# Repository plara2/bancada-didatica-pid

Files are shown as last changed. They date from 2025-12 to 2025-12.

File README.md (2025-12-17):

# 🌡️ Bancada Didática de Controle de Temperatura (Arduino + PID)

Este repositório contém todo o material necessário para reproduzir uma bancada didática de controle térmico de baixo custo. O projeto abrange desde a usinagem da planta mecânica e esquemáticos eletrônicos até o firmware para controle **On-Off** e **PID Digital**.

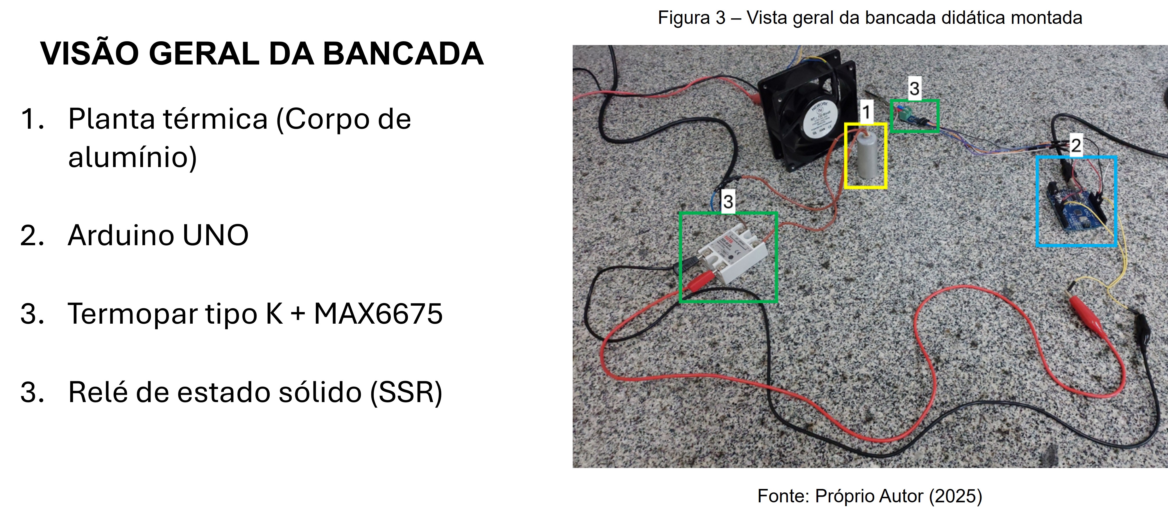
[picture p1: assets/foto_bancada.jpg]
Foto da Bancada Montada

[cite_start]*Figura: Visão geral da bancada com planta térmica, driver de potência e controlador[cite: 84].*

## 🎯 Visão Geral
[cite_start]O projeto utiliza um corpo de prova de alumínio usinado como planta térmica[cite: 92]. [cite_start]O objetivo é demonstrar na prática a diferença entre um controle simples (On-Off) e um controle proporcional-integral-derivativo (PID) sintonizado via método de Ziegler-Nichols[cite: 9].

* [cite_start]**Atuador:** Relé de Estado Sólido (SSR) com técnica de *Slow PWM* (Janela de 8s)[cite: 127, 128].
* [cite_start]**Sensor:** Termopar Tipo K com interface MAX6675[cite: 112, 113].
* [cite_start]**Controlador:** Arduino UNO (Amostragem de 250ms)[cite: 124].

## 📂 Estrutura do Repositório

### 1. Firmware (`/firmware`)
Contém os códigos fonte em C++ para Arduino IDE:
* **Control_PID:** Implementa o algoritmo PID completo usando a biblioteca `PID_v1`. [cite_start]Inclui rotinas de segurança contra falha do sensor e modulação temporal do relé [cite: 254-346].
* **Control_OnOff:** Implementa a lógica de histerese (±0,5°C) para fins comparativos [cite: 347-421].

**Dependências (Bibliotecas):**
* [cite_start][`MAX6675` da Adafruit](https://github.com/adafruit/MAX6675-library) [cite: 228]
* [cite_start][`PID` de Brett Beauregard](https://github.com/br3ttb/Arduino-PID-Library) [cite: 230]

### 2. Hardware Mecânico (`/hardware/mechanical`)
[cite_start]Arquivos para fabricação do corpo de prova cilíndrico (Ø26mm x 61mm)[cite: 93].
* [cite_start]📄 **Desenhos Técnicos:** Dimensões para usinagem dos furos do cartucho e rosca M6 do sensor.
* 🧊 **Modelos 3D:** Arquivos disponíveis em `.f3d` (Fusion 360) e `.step` (Universal).

### 3. Eletrônica (`/hardware/electronics`)
Projeto do circuito de acionamento e leitura.
* Disponível em formato PDF para consulta rápida.
* Arquivos fonte do **KiCad** para edição da PCB/Esquemático.

## 📊 Resultados Comparativos
A bancada permite visualizar claramente a diferença de desempenho entre as técnicas:

| Controle | Comportamento Observado |
| :--- | :--- |
| **On-Off** | Oscilação contínua de ~15°C (pico-a-pico) em torno do Setpoint[cite: 10, 197]. |
| **PID** | Estabilização no Setpoint (50°C) com erro estacionário desprezível após sintonia[cite: 10, 219]. |

Comparação PID vs OnOff
*Exemplo de resposta do sistema controlado via PID[cite: 202].*

## 🚀 Como Reproduzir
1.  **Usinagem:** Utilize os desenhos na pasta `mechanical` para usinar o bloco de alumínio.
2.  **Eletrônica:** Monte o circuito conforme o esquema na pasta `electronics` (Arduino + SSR + MAX6675)[cite: 115].
3.  **Software:** Instale as bibliotecas listadas acima, abra o arquivo `.ino` desejado na Arduino IDE e faça o upload.
4.  **Visualização:** Abra o *Serial Plotter* (115200 baud) para ver as curvas em tempo real[cite: 133].

## 📄 Licença
Este projeto é Open Source. Sinta-se livre para estudar, modificar e contribuir.

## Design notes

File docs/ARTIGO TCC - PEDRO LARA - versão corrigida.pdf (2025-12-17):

Rev. Bras. de Iniciação Científica (RBIC), IFSP Itapetininga, v.12, e025XXX, p. 1-3, 2025.

## Implementação Didática de Controle de Temperatura: Comparação entre PID Digital e On-Off

## Didactic Implementation of Temperature Control: Comparison between Digital PID and On-Off

## Implementación Didáctica de Control de Temperatura: Comparación entre PID Digital y On-Off

Pedro Augusto de Oliveira Lara¹
Cristhiano da Costa Herrera²

Resumo: O ensino de sistemas de controle muitas vezes carece de exemplos práticos que facilitem a visualização da teoria. Este trabalho apresenta o desenvolvimento de uma bancada didática para controle de temperatura, utilizando a plataforma Arduino. O sistema é composto por um corpo de prova de alumínio aquecido por resistência elétrica e monitorado por um termopar. A metodologia consistiu na implementação e comparação de duas estratégias: um controle clássico On-Off e um controlador PID digital, sintonizado pelo método de Ziegler-Nichols. Os resultados demonstraram que o controle On-Off gerou oscilações elevadas de 15°C, enquanto o PID estabilizou o sistema no setpoint de 50°C com erro estacionário desprezível, se comparado com o controle On-Off. Conclui-se que a bancada é eficaz para demonstrar conceitos de controle, embora a elevada inércia térmica da planta exija adaptações para uso em aulas experimentais de curta duração.
Palavras-chave: Controle PID. Bancada Didática. Arduino. Ziegler-Nichols. Controle de Temperatura.

Abstract: The teaching of control systems often lacks practical examples that facilitate the visualization of theoretical concepts. This work presents the development of a didactic test bench for temperature control, using the Arduino platform. The system is composed of an aluminum test body heated by an electrical resistance and monitored by a thermocouple. The methodology consisted of implementing and comparing two strategies: a classical On-Off control and a digital PID controller, tuned by the Ziegler–Nichols method. The results showed that the On-Off control generated high oscillations of 15 °C, while the PID stabilized the system at the 50 °C setpoint with negligible steady-state error when compared to the On-Off control. It is concluded that the test bench is effective for demonstrating control concepts, although the high thermal inertia of the plant requires adaptations for use in short-duration experimental classes.
Keywords: PID Control. Didactic Test Bench. Arduino. Ziegler–Nichols. Temperature Control.

Resumen: La enseñanza de sistemas de control a menudo carece de ejemplos prácticos que faciliten la visualización de la teoría. Este trabajo presenta el desarrollo de una bancada didáctica de bajo costo para el control de temperatura mediante la plataforma Arduino. El sistema consta de un cuerpo de prueba de aluminio calentado por una resistencia eléctrica y monitoreado por un termopar. La metodología incluyó la implementación y comparación de dos estrategias: un control clásico On-Off y un controlador PID digital sintonizado con el método de Ziegler–Nichols. Los resultados mostraron que el control On-Off generó oscilaciones de hasta 15 °C, mientras que el PID estabilizó el sistema en el punto de consigna de 50 °C con error estacionario despreciable. Se concluye que la bancada es eficaz para demostrar conceptos de control, aunque la alta inercia térmica de la planta requiere adaptaciones para su uso en clases experimentales breves.
Palabras-clave: Control PID. Bancada Didáctica. Arduino. Ziegler–Nichols. Control de Temperatura.
Submetido XX/XX/2025 | Aceito XX/XX/202X | Publicado XX/XX/202X

1
Graduando. IFSP. https://orcid.org/0009-0001-8292-560X. E-mail: p.lara@aluno.ifsp.edu.br 2 Doutor. USP. https://orcid.org/0000.0002-9918-2988. E-mail: cristhiano@ifsp.edu.br

Considerações Iniciais

Os sistemas de controle são fundamentais na sociedade atual. Eles aparecem em várias

áreas da ciência da engenharia, desde tarefas simples em operações industriais, como controlar

temperatura ou pressão, até aplicações mais complexas como veículos espaciais (Ogata, 2010;

Nise, 2019).

A história dos sistemas de controle começou no século XVIII, com o regulador

centrífugo de James Watt. Nas décadas de 1940 e 1950 a teoria de controle clássico foi

desenvolvida. Na década de 1960, o apoio dos computadores digitais, permitiu o

estabelecimento da teoria de controle moderno. Por fim, mais recentemente teve lugar a teoria

de controle robusto (Ogata, 2010).

No cenário contemporâneo, especialmente nos últimos 15 anos, a evolução dos sistemas

de controle foi impulsionada pelo aumento exponencial da capacidade computacional e pela

disponibilidade massiva de dados. Novas fronteiras foram estabelecidas além do controle

robusto, com destaque para a consolidação e expansão do Controle Preditivo (MPC) e do

Controle Adaptativo em sistemas complexos e não lineares (Rawlings; Mayne; Diehl, 2017;

Raković; Levine, 2018). Mais recentemente, a integração com a inteligência artificial deu

origem a paradigmas inovadores, como o Controle Baseado em Dados (Data-Driven Control)

e o Controle Baseado em Aprendizagem (Learning-Based Control). Essas abordagens

modernas utilizam algoritmos de aprendizado de máquina para modelar dinâmicas

desconhecidas e otimizar o desempenho em tempo real, garantindo segurança e eficiência em

ambientes incertos (Hou; Wang, 2017; Brunton; Kutz, 2022; Hewing; Wabersich; Menner;

Zeilinger, 2020).

Mesmo após décadas de desenvolvimento das teorias de sistemas de controle, ainda

existem debates sobre como ensinar melhor esse conteúdo e preparar engenheiros para os

desafios práticos do controle de processos. Para muitos estudantes, a ligação entre as teorias

matemáticas e a prática com plantas reais ainda é bastante abstrata (Rossiter; Serbezov; Visioli;

Záková; Huba, 2020).

Por isso, estudar métodos práticos para o ensino de sistemas de controle se tornou

essencial. A criação de bancadas didáticas ajuda a aproximar teoria e prática, sendo uma

ferramenta importante no ensino de engenharia. Neste trabalho, o objetivo foi desenvolver um

sistema de controle de temperatura, usando um microcontrolador como controlador

Proporcional-Integral-Derivativa (PID), para que os alunos de Engenharia do Instituto Federal

de São Paulo, campus Itapetininga, possam entender de forma visual e prática os efeitos de cada

ação de controle.

Fundamentação Teórica

A Estratégia de Controle PID

O controlador PID é muito usado na automação industrial e na pesquisa acadêmica

porque é simples de implementar e atende a vários requisitos de desempenho (Nise, 2019). Em

um sistema típico, o controlador age sobre o erro, que é a diferença entre o valor de referência

(setpoint) e a variável medida do processo. A Figura 1 ilustra o controle PID.

Figura 1: Diagrama de blocos de um sistema de controle com controlador PID.

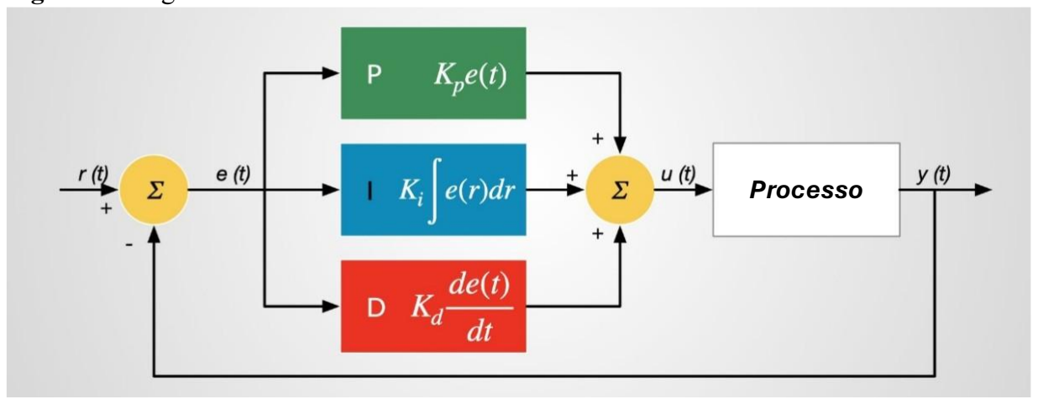
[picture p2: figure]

Fonte: Adaptado (Mcaleer, 2023).

O controle PID reúne três ações principais, e cada uma tem um papel diferente no

comportamento do sistema (Ogata, 2010):

Ação Proporcional (P): Multiplica o erro por uma constante denominada ganho

proporcional com o objetivo de ajustar a velocidade de resposta do sistema. Um ganho

proporcional elevado reduz o tempo de acomodação, mas pode introduzir sobressinal e,

isoladamente, não é capaz de eliminar o erro em regime permanente.

Ação Integral (I): acumula o erro ao longo do tempo, atuando para elimina-lo em

regime permanente e garantindo precisão na saída controlada. A intensidade dessa correção é

definida pelo ganho integral, contudo, se ajustado em excesso, esse ganho tende a desestabilizar

o sistema, provocando oscilações crescentes e aumentando o tempo de assentamento.

Ação Derivativa (D): Atua sobre a taxa de variação do erro, antecipando tendências e

contribuindo para a estabilidade, reduzindo oscilações e o sobressinal. No entanto, um ganho

derivativo excessivo amplifica ruídos de alta frequência presentes no sinal de medição, o que

pode levar à instabilidade e a uma atuação errática.

O equilíbrio entre essas três ações garante que o sistema controlado responda de forma

adequada. No ensino, o controle PID é especialmente útil porque o ganho de cada ação pode

ser ajustado separadamente, permitindo que os estudantes vejam diretamente como cada ação

afeta o comportamento da planta (Daga; Lenzi; Quadros, 2019).

Implementação Digital do Controlador PID

Em conjuntos de desenvolvimento baseados em microcontroladores como o Arduino, o

processamento dos sinais é realizado em tempo discreto. O sinal digital opera em intervalos

fixos de amostragem, ou seja, o controlador lê o sensor, calcula a saída e atua no processo em

intervalos regulares (Ogata, 2010).

A estrutura fundamental de controle em malha fechada continua sendo a mesma

apresentada no diagrama de blocos da Figura 1.

Método de Sintonia Prática: Ziegler-Nichols

No método de sintonia de Ziegler-Nichols por ganho e período críticos em malha

fechada, o controlador deve ser ajustado inicialmente apenas com a ação proporcional ativada,

enquanto as ações integral e derivativa permanecem desligadas. O ganho proporcional é

aumentado aos poucos até que o sistema apresente oscilações sustentadas, ou seja, oscilações

periódicas com amplitude constante (Nise, 2019; Daga; Lenzi; Quadros, 2019).

O valor do ganho que causa esse comportamento é chamado de ganho crítico (Kcr
), e o

período das oscilações é chamado de período crítico (Tcr
). Com esses dois parâmetros, Ziegler

e Nichols criaram fórmulas empíricas para definir os ganhos de cada ação de controle, buscando

uma resposta rápida e com bom amortecimento (Ogata, 2010). A Figura 2 mostra as oscilações

sustentadas.

Figura 2: Resposta típica do sistema em malha fechada para determinação de Kcr e Tcr, destacando a forma de onda das oscilações sustentadas.

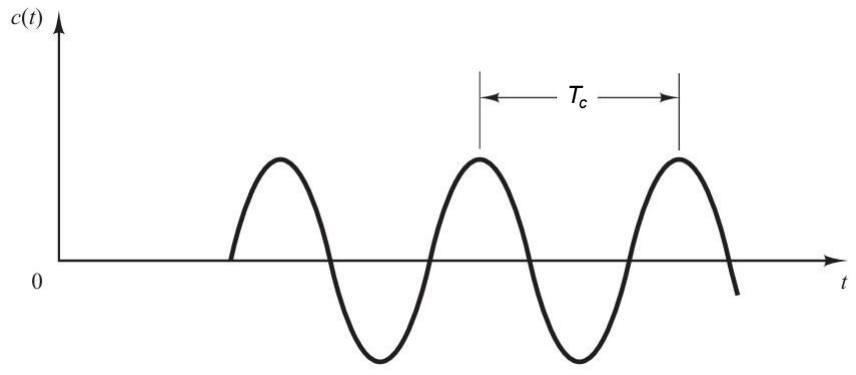
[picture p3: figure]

Fonte: Adaptado (Ogata, 2010).

A Tabela 1 apresenta as relações clássicas entre os parâmetros Kcr e Tcr e os ganhos correspondentes do controlador PID.

Tabela 1 – Parâmetro clássicos do método de Ziegler-Nichols (malha fechada).

Tipo de
controlador
| Kp | Ti | Td
P | 0,5 ∗ Kcr | – | –
PI | 0,45 ∗ Kcr | Tcr
| | 1,2 | –
PID | 0,6 ∗ Kcr | Tcr
| | 2 | 0,125 ∗ Tcr

Fonte: Adaptado (Ogata, 2010).

Como esse método permite que o controlador possa ser sintonizado sem que seja

necessário um modelo prévio da planta controlada, ele desponta como um bom recurso para o

ensino da técnica de controle PID. Observar as oscilações sustentadas e o comportamento

dinâmico durante o ajuste do ganho proporcional ajuda a entender de forma visual e imediata

os efeitos de estabilidade e amortecimento, o que aumenta o valor pedagógico do experimento

(Daga; Lenzi; Quadros, 2019; Nascimento, 2025).

Metodologia

Esta seção descreve os procedimentos de construção, instrumentação, programação e

testes da bancada didática para controle de temperatura. O sistema proposto consiste em uma

malha de controle em tempo discreto, gerenciada por um microcontrolador, voltada para o

estudo experimental de controladores digitais do tipo PID

Visão geral do sistema

O projeto consiste em uma bancada didática, operando em malha fechada. Diferente de

sistemas puramente analógicos, a lógica de controle é processada via software. O sistema é

composto por três blocos principais ilustrados na Figura 3.

Figura 3: Vista geral da bancada didática montada, destacando a planta térmica, o circuito de acionamento e o microcontrolador.

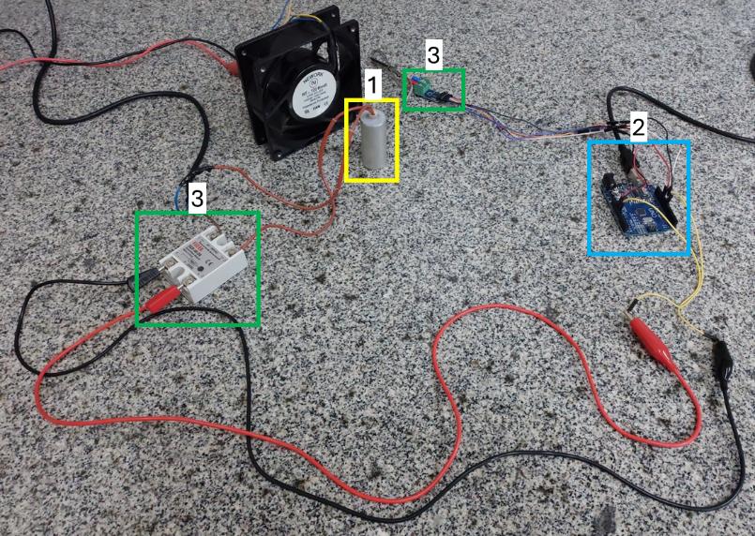
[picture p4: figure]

Fonte: Próprio Autor (2025).

1. A planta térmica: O processo físico a ser controlado, constituído por um bloco

de alumínio aquecido;

2. O controlador digital: Implementado em uma placa de desenvolvimento Arduino

UNO, responsável pela aquisição de dados, execução do algoritmo PID e sinal

de atuação;

3. Interface e Atuação: Composta pelo módulo de leitura de temperatura e pelo

Relé De Estado Sólido (SSR) para modulação de potência.

O fluxo de controle segue a lógica de realimentação negativa: o sensor lê a temperatura

do processo (PV), o microcontrolador calcula o erro em relação ao setpoint (SP) e gera um sinal de controle. Esse sinal aciona o relé de estado sólido, que modula a entrega de energia ao

cartucho aquecedor.

Construção da planta

A planta térmica consiste em um corpo de prova cilíndrico usinado em alumínio maciço,

material escolhido por sua facilidade de usinagem e disponibilidade no campus. O corpo de

prova possui dimensões de 26 mm de diâmetro e 61 mm de comprimento, medidas definidas

visando a economia de recursos materiais do campus, mas ainda suficientes para comportar o

cartucho aquecedor disponível.

Para a integração dos elementos de aquecimento e sensoriamento, foram realizadas

operações de usinagem detalhadas conforme o projeto modelado em software CAD (Fusion

360):

Alojamento do Aquecedor: Foi usinado um furo central cego com 12,6 mm de

diâmetro e 47 mm de profundidade. Esta medida foi definida para acomodar o cartucho

aquecedor (12,5 mm de diâmetro e 50 mm de comprimento) com uma folga de

aproximadamente 0,1 mm, a qual foi preenchida com pasta térmica para garantir o acoplamento

térmico ideal.

Alojamento do Sensor: Foi realizado um furo roscado M6 com 13 mm de

profundidade. A rosca permiteu a fixação firme do termopar tipo K (com ponta blindada em

aço inox e rosca M6), reduzindo possíveis interferências na leitura de temperatura.

A Figura 4 mostra detalhes dos alojamentos do Aquecedor e do Sensor.

Figura 4: Detalhamento do corpo de prova modelado em software CAD (Fusion 360).

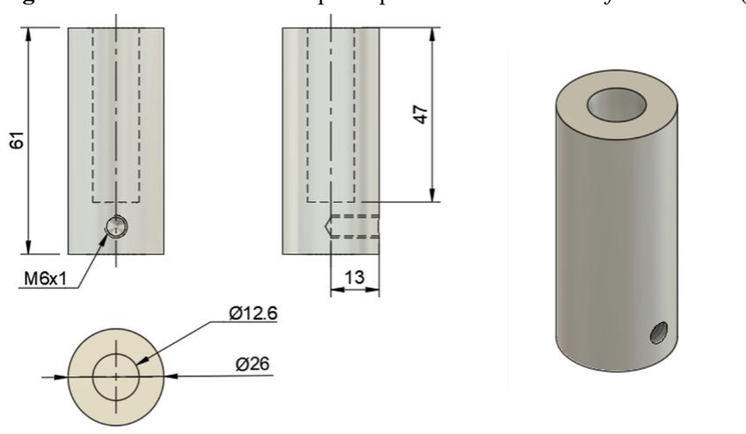
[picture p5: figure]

Fonte: Próprio Autor (2025).

Figura 5: Cartucho elétrico e ponta do termopar com rosca M6

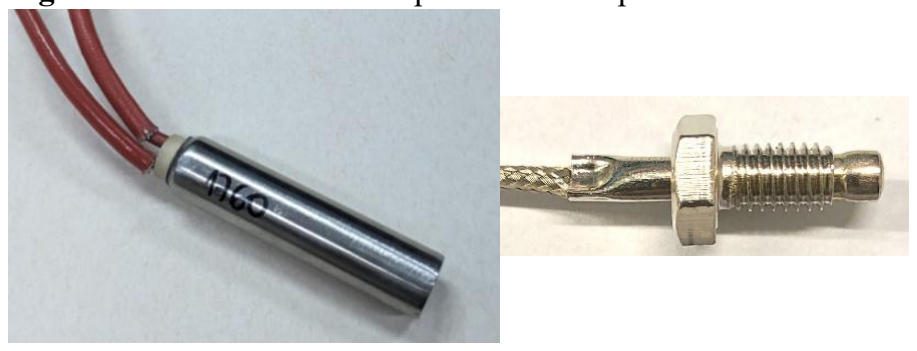
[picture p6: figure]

Fonte: Próprio Autor (2025)

Como mecanismo de resfriamento forçado, foi posicionado um cooler de 120 mm

direcionado ao corpo de prova, permitindo alterar a dinâmica do sistema e reduzir a inércia

térmica para resfriamentos durante os ensaios.

Hardware e Instrumentação Eletrônica

A instrumentação eletrônica é responsável pela interface entre o mundo físico e o

controlador digital. A Figura 6 ilustra os componentes do Hardware.

Atuador: A potência entregue ao sistema é controlada por um Relé de Estado Sólido

(SSR-40DA Fotek). O SSR recebe um sinal de controle de 5V do microcontrolador e chaveia

a tensão alternada da rede para a resistência. A escolha do SSR justifica-se pela implementação

de uma estratégia de controle proporcional ao tempo (Time-Proportional Control). Nesta

técnica, a potência média entregue à carga é modulada variando-se o tempo de condução dentro

de uma janela fixa (neste trabalho, 8 s), eliminando os desgastes mecânicos e ruídos acústicos

que seriam críticos em relés eletromecânicos submetidos a este regime de chaveamento.

Sensor e Condicionamento: A medição é realizada por um Termopar Tipo K, operando

na faixa de interesse do projeto. O sinal analógico do termopar (na ordem de milivolts) é

processado pelo módulo MAX6675, que realiza a compensação de junta fria e converte o sinal

para um formato digital (protocolo SPI) com resolução de 0,25°C.

Unidade de Processamento: Um Arduino UNO atua como a unidade central,

comunicando-se com o MAX6675 via barramento SPI e executando o algoritmo de controle.

Figura 6: Diagrama esquemático das conexões: Arduino ligado ao MAX6675 (pinos SPI: SCK, CS, SO) e ao SSR (pino digital).

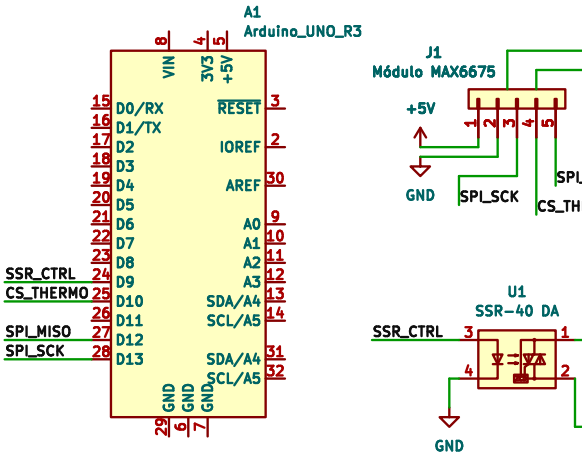
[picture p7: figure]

Fonte: Próprio Autor (2025).

Implementação do Firmware e Controlador Digital

O controle e aquisição de dados foram implementados em linguagem C++ utilizando o

Ambiente de Desenvolvimento Integrado (IDE) do Arduino. O firmware baseia-se em duas

bibliotecas principais de código aberto: max6675.h (Adafruit Industries, 2023), responsável

pela comunicação SPI com o sensor; e PID_v1.h (Beauregard, 2017), que implementa o

algoritmo de controle robusto.

O algoritmo implementa a equação contínua do PID:

u(t) = Kpe(t) + Ki∫ e(t)dt + Kd

de(t)
dt
Estruturou-se o ciclo de processamento visando o determinismo temporal e a robustez

operacional, garantindo que as tarefas críticas de leitura e atuação sejam executadas dentro das

janelas de tempo preestabelecidas:

Amostragem e Segurança: O sistema opera com um tempo de amostragem (Ts
) de 250

ms, valor limitado pelo tempo mínimo de conversão exigido pelo módulo MAX6675. A cada

ciclo, o microcontrolador verifica a integridade da leitura do sensor. Caso ocorra falha no

termopar (detectada pela função isnan), o sistema aciona uma rotina de segurança que força o

desligamento imediato do SSR para evitar o descontrole térmico.

Técnica de Atuação (“Slow PWM”): Dado que o atuador é um Relé de Estado Sólido

controlando um sistema térmico de dinâmica lenta, não se utiliza o PWM de hardware de alta frequência. Em vez disso, implementou-se uma técnica de Controle Proporcional ao Tempo

com uma janela (Window Size) de 8000 ms (8 segundos). O valor calculado pelo PID determina

a fração de tempo que o relé permanece ligado dentro desta janela.

O código-fonte completo desenvolvido para o controlador PID, incluindo as

configurações da biblioteca e a lógica de atuação por janela de tempo, encontra-se disponível em repositório digital público³

Procedimentos Experimentais

Os ensaios foram divididos em etapas para identificação e validação do sistema. A

aquisição de dados foi realizada via interface serial (USB) a uma taxa de 115200 bits por

segundo. O firmware foi programado para transmitir, a cada 1000 ms (1 segundo), uma string

em formato de valores separados por vírgulas contendo o tempo decorrido, a temperatura do

processo e o setpoint.

Para sintonia do controlador e determinação dos parâmetros proporcional (Kp), integral

(Ki

) e derivativo (Kd), aplicou-se o método de Ziegler-Nichols em malha fechada (método do

ganho crítico). Para isso foi definido Ki e Kd nulos, mantendo-se apenas a ação proporcional,

O valor de Kp foi incrementado gradativamente até que o sistema apresentasse uma oscilação

sustentada de amplitude constante. O monitoramento da resposta do sistema foi realizado por

meio da ferramenta Serial Plotter do ambiente de desenvolvimento (IDE) do Arduino.

Após atingir a oscilação sustentada, foram identificados os instantes de temperatura

máxima (picos de oscilação) para o cálculo do intervalo médio entre os ciclos, definindo-se

assim o período crítico (Tcr). Os valores obtidos experimentalmente para o ganho crítico (Kcr)

e o período crítico (Tcr) foram:

Kcr = 90.0

Tc = 168 s

Com base nos valores experimentais de Kcr e Tcr, os parâmetros do controlador PID

foram calculados utilizando as regras de sintonia clássicas de Ziegler-Nichols, conforme as

equações a seguir:
Kp = 0,60 ⋅ Kcr

Ti = 0,50 ⋅ Tcr

3 Disponível em: https://github.com/plara2/bancada-didatica-pid

Td = 0,125 ⋅ Tcr

Substituindo os valores obtidos (Kcr = 90,0 e Tcr = 168 s):

Kp = 0,60 ⋅ 90,0 = 54,0

Ti = 0,50 ⋅ 168 = 84,0 s

Td = 0,125 ⋅ 168 = 21,0 s

Visto que o algoritmo de controle utilizado (biblioteca PID v1 para Arduino)

implementa a equação na forma paralela independente, faz-se necessária a conversão das

constantes de tempo (Ti e Td) para os ganhos integral (Ki

) e derivativo (Kd):

Ki =

Kp
Ti

=

54,0
84,0

≈ 0,643

Kd = Kp ⋅ Td = 54,0 ⋅ 21,0 = 1134,0

Portanto, os parâmetros finais configurados no controlador foram: Kp = 54,0; Ki =

0,64 e Kd = 1134,0.

Ensaio Comparativo: Controle On-Off

Para estabelecer uma linha de base de desempenho da planta e verificar sua validade

enquanto ferramenta para que um estudante possa compreender as particularidades do controle

PID, também foi implementada uma estratégia de controle do tipo On-Off (duas posições). Este

experimento tem como objetivo evidenciar as limitações deste método, especificamente a

oscilação em torno do setpoint, devido à inércia térmica do bloco de alumínio.

O algoritmo foi desenvolvido mantendo-se a mesma estrutura de hardware e bibliotecas

de leitura (max6675.h), alterando-se apenas a lógica de atuação. Para evitar o chaveamento

excessivo do relé (efeito de chattering) devido a ruídos na leitura do sensor, implementou-se

uma banda de histerese (H) de ± 0,5 °C em torno do setpoint.

A lógica de controle, executada com um período de amostragem de 1000 ms (1,0 s),

segue as condições descritas abaixo:
{
1 (Ligado), se T(t) ≤ SP − H 0 (Desligado), se T(t) ≥ SP + H u (t − 1), caso contrário

Onde:

- u(t) é o estado do atuador (SSR);
- T(t) é a temperatura lida no instante atual;

- SP é o setpoint definido (50,0 ºC);
- H é a histerese definida no código (0,5 ºC);

Dada a grande inércia térmica do corpo de prova, frequências de amostragem elevadas

tornam-se dispensáveis para a estabilidade do sistema de controle On-Off, por isso foi

determinado o período de amostragem de 1000 ms. Ressalta-se ainda que o foco experimental

não reside na comparação de desempenho entre On-Off e PID, mas na apresentação do

potencial da plataforma em ilustrar didaticamente os conceitos fundamentais de cada técnica.

Dessa forma, o aquecedor é acionado somente quando a temperatura cai para 49,5 ºC e

desligado apenas quando atinge 50,5 ºC. Assim como no controlador PID, os dados de tempo,

temperatura e estado do atuador foram transmitidos via porta serial para registro e posterior

comparação das curvas de resposta temporal.

O algoritmo implementado para o controle On-Off, com a lógica de histerese e aquisição de dados, também pode ser consultado integralmente no repositório online do projeto³

Resultados

A figura 7 apresenta o comportamento da bancada didática quando ela é empregada para

produzir uma oscilação sustentada com o objetivo de sintonizar o controlador por meio do

método de Ziegler-Nichols. Esse comportamento dinâmico foi obtido ajustando o controlador

PID para ação puramente proporcional com ganho crítico Kcr = 90.

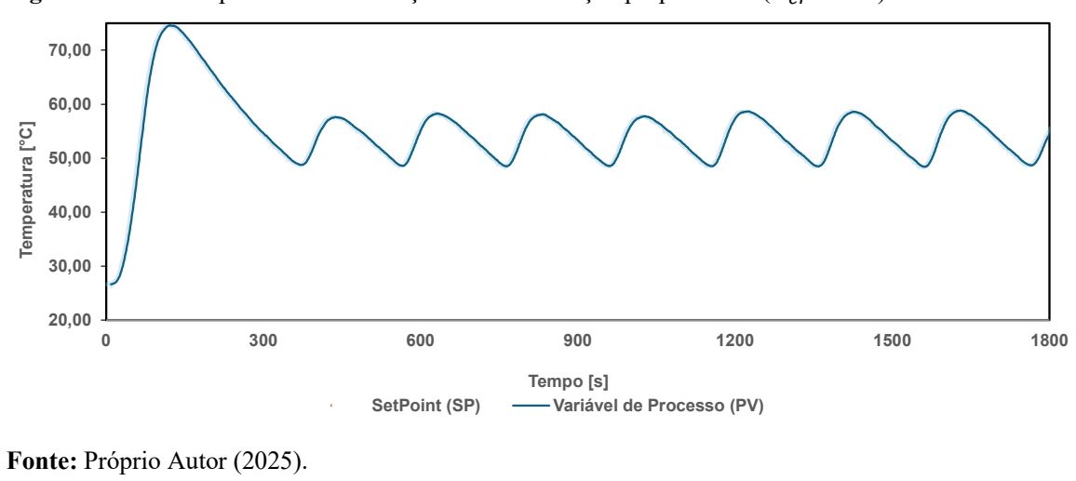
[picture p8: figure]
Fonte: Próprio Autor (2025).

Figura 7: Gráfico representando oscilação obtida com ação proporcional (Kcr = 90).

Na Figura 7 é possível observar que a bancada didática apresenta o comportamento

esperado da aplicação de um ganho elevado em um sistema com inércia térmica significativa,

quando a acumulação da energia térmica continua elevando a temperatura mesmo após o corte

do sinal de controle. Inicialmente, partindo da temperatura ambiente, o sistema apresenta um

sobressinal expressivo, atingindo um pico próximo a 75 ºC.

Após o regime transitório inicial (aproximadamente t > 900 s), observa-se que as

oscilações se tornam periódicas e de amplitude constante em torno do setpoint de 50∘C,

caracterizando a oscilação sustentada necessária para a aplicação do método de Ziegler-Nichols.

A assimetria observada entre os ciclos de aquecimento (subida rápida) e resfriamento (descida

mais lenta) evidencia a não-linearidade natural do processo térmico: o aquecimento é forçado

pela resistência elétrica (ativo), enquanto o resfriamento depende majoritariamente da troca

térmica com o ambiente e da atuação do cooler (passivo/forçado).

A resposta da bancada didática apresentada na Figura 7 permite que estudantes realizem

a mensuração do período crítico (Tcr). No caso em exemplo, a mensuração poderia ser feita pela

medição do intervalo de tempo entre os picos consecutivos da região de oscilação estável. Esse

intervalo de tempo varia de 1200 s a 1800 s, com média em 168 s.

Esses dois parâmetros experimentais (Kcr = 90 e Tcr = 168 s) permitiram aos estudantes

realizar os cálculos dos ganhos Kp, Ki e Kd seguindo os parâmetros apresentados na Tabela 1.

Controle On-Off

A Figura 8 apresenta o desempenho do sistema operando com o controlador On-Off. A

análise da curva de resposta revela as limitações intrínsecas desta estratégia para o controle da

planta térmica construída.

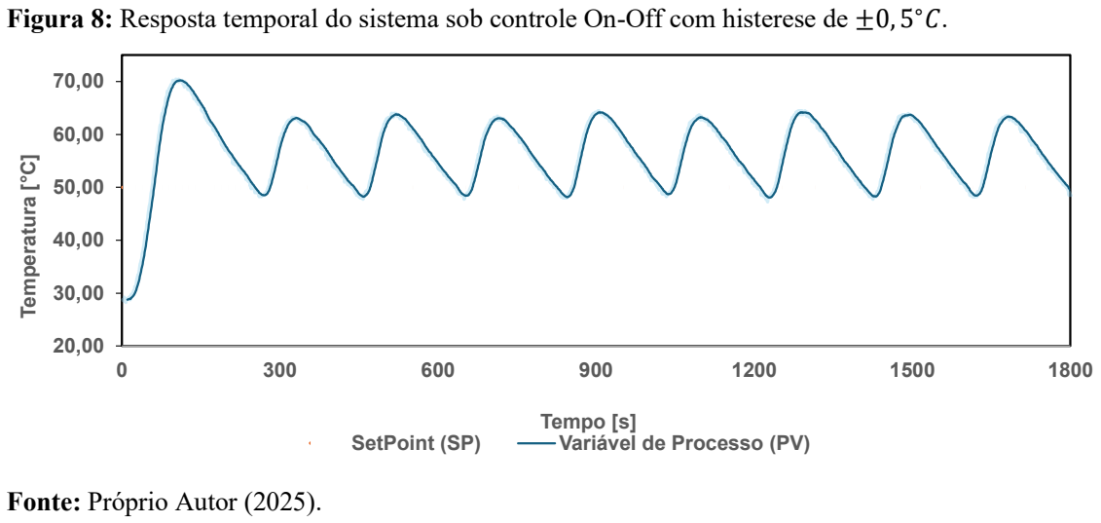
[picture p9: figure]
Fonte: Próprio Autor (2025).

Figura 8: Resposta temporal do sistema sob controle On-Off com histerese de ±0, 5

Primeiramente, observa-se um regime transitório agressivo. Ao partir da temperatura ambiente (≈ 28∘C), o atuador permanece ligado em potência máxima até cruzar o setpoint

(50∘C). Devido à elevada inércia térmica do bloco de alumínio e ao atraso de transporte entre

o elemento aquecedor e o sensor, a temperatura continua subindo abruptamente mesmo após o desligamento do relé, atingindo um pico inicial próximo a 70∘C. Isso representa um sobressinal

de aproximadamente 40% em relação ao valor desejado.

Como esperado, o sistema não se estabiliza em regime permanente, mas permanece em

um ciclo limite (oscilação contínua) com perfil característico de “dente de serra”. Esse

comportamento, permitiria que estudantes discutissem as diversas particularidades da

assimetria na forma de onda, como:

1. Subidas rápidas: Ocorrem quando o relé é acionado, indicando que a potência do

cartucho aquecedor é elevada para a massa do sistema, causando aquecimento rápido.

2. Descidas lentas: Ocorrem quando o relé desliga e o sistema resfria passivamente

(troca com o ambiente) e com auxílio do cooler.

A banca didática demonstra com fidelidade que, mesmo com uma banda de histerese

configurada para ±0, 5

∘C (desligando em 50,5 ºC e ligando em 49,5 ºC), a inércia térmica não

permite que o sistema estabilize próximo ao setpoint. A temperatura deve oscilar entre máximos

de aproximadamente 63 ºC e mínimos de 49 ºC, resultando em uma amplitude de oscilação

pico-a-pico (ΔT) de cerca de 15ºC.

Esse resultado confirma que a bancada didática é capaz de oferecer aos estudantes uma

compreensão efetiva de que o controle On-Off, embora simples, apresenta uma grande variação

de temperatura, inviabilizando a manutenção precisa do setpoint. Essa compreensão, torna mais

concreta a necessidade de implementação do controlador PID para modulação proporcional da

potência em aplicações que não tolerem variações tão amplas.

Controle PID

A Figura 9 apresenta a resposta do sistema operando com o controlador PID digital,

utilizando os parâmetros obtidos pelo método de Ziegler-Nichols (Kp = 54,0;Ki = 0,64;Kd =

1134,0) e a técnica de atuação por janela de tempo (PWM de baixa frequência).

Figura 9: Resposta temporal do sistema em malha fechada com controlador PID sintonizado (Kp =

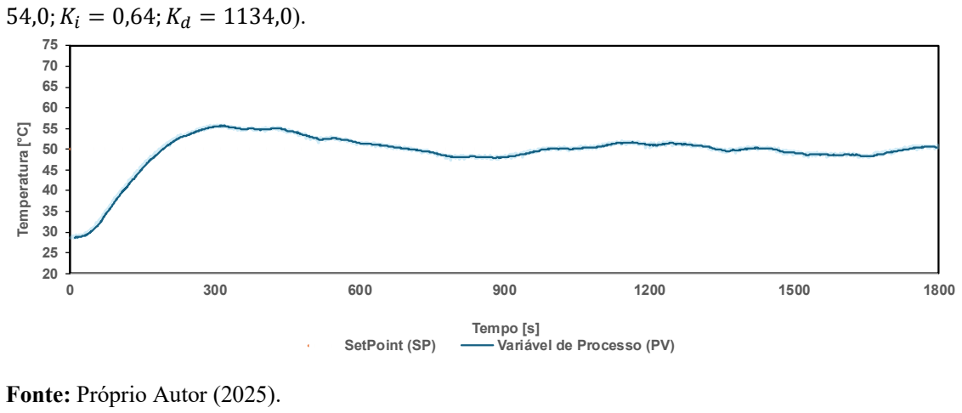
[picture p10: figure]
Fonte: Próprio Autor (2025).

Analisando o regime transitório, observa-se que também nesse cenário, a bancada

didática mostrou-se capaz de reproduzir o comportamento esperado. O sistema alcança o valor

de setpoint (50 ºC) pela primeira vez em aproximadamente 185 s segundos. A resposta do

sistema também apresenta o sobressinal previsto pela teoria de Ziegler-Nichols, que, ao

priorizar a velocidade de resposta, permite uma margem de oscilação inicial (critério de

decaimento de um quarto). A temperatura atinge um pico máximo de aproximadamente 55 ºC

no instante t ≅ 390 s, representando um desvio percentual de cerca de 11% acima do setpoint.

A Figura 9 comprova que a bancada didática pode proporcionar que os estudantes

discutam o efeito dos termos integral e derivativo sobre a resposta do sistema. Neste experimento, por exemplo, a Ação Derivativa (Kd) amorteceu as oscilações, impedindo que o

sistema se tornasse instável ou mantivesse o comportamento oscilatório apresentado no ensaio

de ganho crítico. Já a Ação Integral (Ki) atuou para dirimir o erro em regime permanente.

Nesse experimento, o sistema entrou em regime permanente passados 1000 s. Esse

resultado permitiria que estudantes visualizassem a diferença do regime permanente obtido no

controle On-Off, que permite que a temperatura oscile em torno do alvo, e obtido com o controle

PID, que mantém a variável de processo (PV) aderente ao setpoint. As pequenas flutuações

observadas no final do gráfico são inerentes ao sistema devido a ruídos de medição, dificuldade

de resposta a perturbações térmicas ambientais e limitações da própria resolução do sensor

termopar utilizado, característica que também pode ser explorada no processo formativo..

Considerações Finais

O presente trabalho cumpriu o objetivo de desenvolver e validar uma bancada didática

para o ensino de sistemas de controle digitais, consolidando a aplicação prática de controladores

PID em microcontroladores. A integração entre o ambiente de programação, a instrumentação

eletrônica e a planta térmica permitiram demonstrar, de forma tangível, as etapas fundamentais

de um projeto de engenharia de controle: desde a aquisição de dados e identificação de sistemas

até a sintonia e validação da malha fechada.

Quanto ao valor didático do sistema, os resultados experimentais confirmaram que a

bancada didática oferece aos estudantes o contato com as particularidades tanto da estratégia

PID quanto do controle On-Off. Com o seu emprego, torna-se concreta a percepção de que a

estratégia de duas posições resulta em um ciclo limite com oscilações de amplitude elevada que

podem ser inadequadas para processos que exigem precisão. Ao mesmo tempo, a bancada

apresenta a característica do controle PID digital, sintonizado pelo método de Ziegler-Nichols,

de estabilizar a temperatura bem próxima do setpoint com uma pequena oscilação, diminuindo

o erro em regime permanente e amortecendo as oscilações transientes. O comportamento do

sistema valida o algoritmo implementado e a metodologia de projeto baseada na técnica de

Slow PWM para atuação em relés de estado sólido para o desenvolvimento de bancadas dessa

natureza.

Entretanto, a análise dinâmica dos ensaios revelou uma limitação importante quanto à

aplicabilidade pedagógica do sistema em aulas experimentais de curta duração. A elevada

inércia térmica do corpo de prova de alumínio resultou em constantes de tempo longas, exigindo janelas de observação superiores a 1800 segundos (30 minutos) para a realização completa de

procedimentos como a determinação do ganho crítico (Kcr) e a estabilização da resposta. Essa

característica temporal impõe desafios logísticos para a disciplina, visto que o tempo necessário

para aquecimento, perturbação e resfriamento pode exceder a disponibilidade de horas-aula

convencionais.

Visando superar essa barreira temporal, sugere-se como trabalho futuro o

desenvolvimento de uma planta baseada no aquecimento de fluidos em fluxo contínuo (similar

a sistemas de aquecimento de água de passagem). Diferentemente de massas sólidas estáticas,

sistemas de fluxo dinâmico apresentam resposta significativamente mais rápida às variações de

potência. Essa alteração na natureza física do processo permitiria reduzir drasticamente o tempo

de acomodação e resfriamento, viabilizando a realização de múltiplos ciclos de sintonia e testes

de perturbação dentro do período regular de uma aula experimental.

Referência

ADAFRUIT INDUSTRIES. MAX6675 Library: Arduino library for interfacing with MAX6675 thermocouple amplifier. Versão 1.1.2. Nova Iorque, 2023. Disponível em: https://github.com/adafruit/MAX6675-library. Acesso em: 15 out. 2025.

BEAUREGARD, Brett. Arduino PID Library. Versão 1.2.1. [S. l.: s. n.], 2017. Disponível em: https://github.com/br3ttb/Arduino-PID-Library. Acesso em: 15 out. 2025.

BRUNTON, Steven L.; KUTZ, J. Nathan. Data-driven science and engineering: Machine learning, dynamical systems, and control. Cambridge University Press, 2022.

DAGA, Alisson L.; LENZI, Marcelo K.; QUADROS, Thiago D. de. Módulo didático para estudo de controlador PID analógico. In: CONGRESSO DE ENGENHARIA DA UFPR, 2019, Curitiba. Curitiba: Universidade Federal do Paraná, 2019. p. 40–47.

HEWING, Lukas; WABERSICH, Kim P.; MENNER, Marcel; ZEILINGER, Melanie N. Learning-Based Model Predictive Control: Toward Safe Learning in Control. Annual Review of Control, Robotics, and Autonomous Systems, v. 3, p. 269-296, maio 2020. DOI: 10.1146/annurev-control-090419-075625. Disponível em: https://doi.org/10.1146/annurev-control-090419-075625. (https://doi.org/10.1146/annurev-control-090419-075625) Acesso em: 13 dez. 2025.

HOU, Zhongsheng; WANG, Zhongsheng. Data-Driven Control and Learning Systems. IEEE Transactions on Industrial Electronics, v. 64, n. 5, p. 4070-4075, 2017.

HOTZ, Jéssica dos Santos. Bancada didática para controle de nível e temperatura. 2014. Trabalho de Conclusão de Curso (Graduação em Engenharia Eletrônica) . Universidade Tecnológica Federal do Paraná.

LAGE, Vinícius Nunes. Desenvolvimento de um controlador PID para estabilização de uma plataforma com dois graus de liberdade. 2016.

MCALEER, Kevin. PID Controllers. KevsRobots, 13 mar. 2023. Disponível em: https://www.kevsrobots.com/resources/how_it_works/pid-controllers.html. Acesso em: 16 dez. 2025.

NASCIMENTO, João Vitor Ferreira. Projeto de Controlador PID para Controle de Temperatura e Implementação de Técnicas para Otimização dos Resultados. 2025. Monografia (Graduação em Engenharia de Controle e Automação) – Escola de Minas, Universidade Federal de Ouro Preto, Ouro Preto, 2025.

NISE, Norman S. Control systems engineering. John Wiley & Sons, 2019.

OGATA, Katsuhiko. Engenharia de controle moderno. 5. ed. São Paulo: Pearson Prentice Hall, 2010.

RAKOVIĆ, Saša V.; LEVINE, William S. (Eds.). Handbook of Model Predictive Control. New York: Birkhäuser, 2018.

RAWLINGS, James B.; MAYNE, David Q.; DIEHL, Moritz M. Model Predictive Control: Theory, Computation, and Design. 2. ed. Santa Barbara: Nob Hill Publishing, 2017.

ROSSITER, J. A.; SERBEZOV, A.; VISIOLI, A.; ZÁKOVÁ, K.; HUBA, M. A survey of international views on a first course in systems and control for engineering undergraduates. IFAC Journal of Systems and Control, v. 13, art. 100092, 2020. DOI: 10.1016/j.ifacsc.2020.100092. Disponível em: https://doi.org/10.1016/j.ifacsc.2020.100092. Acesso em: 14 dez. 2025.

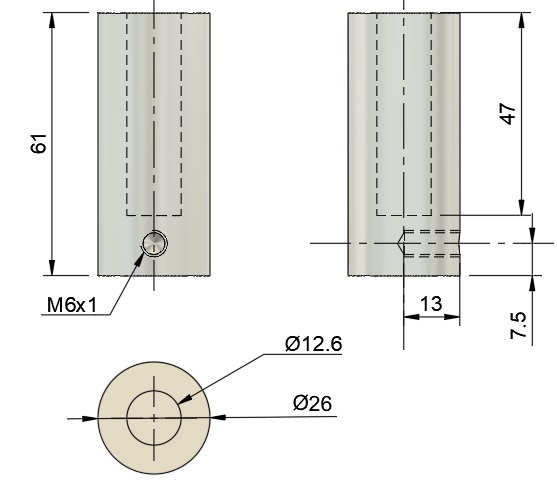
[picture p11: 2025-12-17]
hardware/mechanical/Desenho 2D.jpg

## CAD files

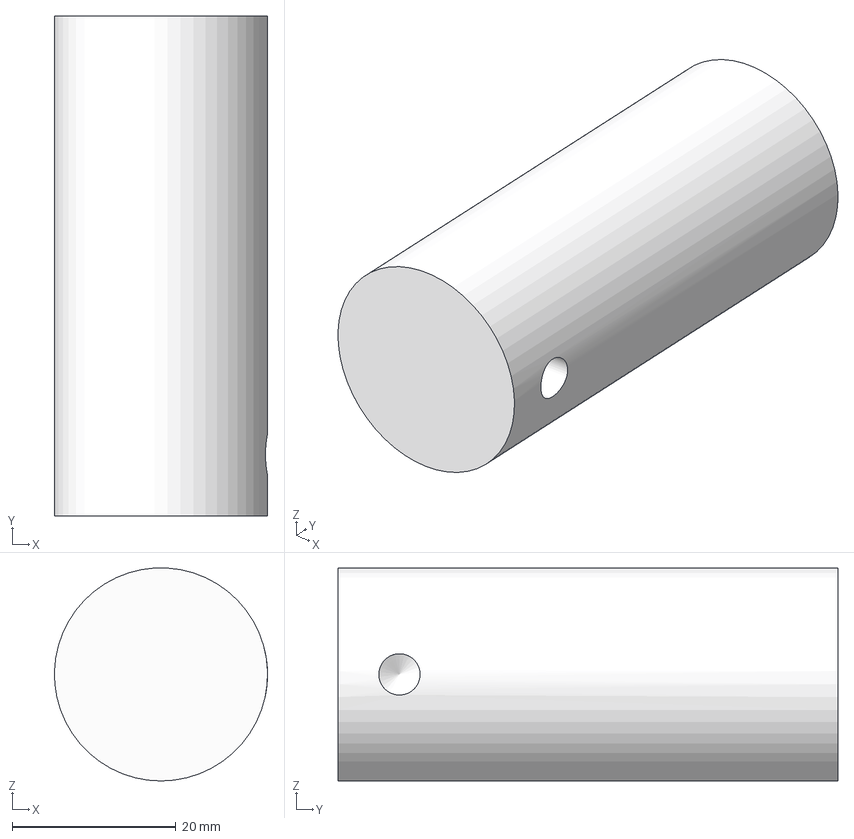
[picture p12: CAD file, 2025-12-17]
hardware/mechanical/Corpo de prova.step
26.0 x 61.0 x 26.0 mm

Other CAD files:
hardware/mechanical/Corpo de prova.f3z

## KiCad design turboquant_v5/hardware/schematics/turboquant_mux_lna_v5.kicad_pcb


Board: 4 copper layers, 100.0 x 80.0 mm, 25 parts (0 on the bottom side), 3 nets.

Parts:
F1: 2A; Fuse_1206_3216Metric
J1: 12V_Input; TerminalBlock_bornier-2_P5.08mm
J2: TX_BUS; SMA_EDGE
J3: E1_GPIO; PinHeader_2x10_P2.54mm_Vertical
J4: RX0_OUT; SMA_EDGE
J5: RX1_OUT; SMA_EDGE
Q9, Q10, Q11, Q12, Q13, Q14, Q15, Q16: IRF830; TO-220-3_Vertical
U1: LM7805; TO-252-2
U2: AMS1117-3.3; SOT-223-3_TabPin2
U3, U4: DG408; SOIC-16_3.9x9.9mm_P1.27mm
U5: 74HCT595; SOIC-16_3.9x9.9mm_P1.27mm
U6, U7: OPA1641; SOIC-8_3.9x4.9mm_P1.27mm
U8, U9, U10, U11: TC4427; SOIC-8_3.9x4.9mm_P1.27mm

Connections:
+5V: U1.3, U2.3
+12V: F1.1, F1.2, J1.1, U1.1
GND: J1.2, J2.2, J4.2, J5.2, U1.2, U2.1

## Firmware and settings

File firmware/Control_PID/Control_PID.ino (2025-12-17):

#include <SPI.h>
#include <max6675.h>
#include <PID_v1.h>

// MAX6675
int thermoSO  = 12;
int thermoCS  = 10;
int thermoSCK = 13;
MAX6675 thermocouple(thermoSCK, thermoCS, thermoSO);

// SSR
#define RELAY_PIN 9

// PID
double Setpoint, Input, Output;

// PARA ACHAR KU E TU (Ziegler–Nichols)
double Kp = 54.0;   // ajuste esse valor até oscilar
double Ki = 0.64;     // Z–N etapa 1
double Kd = 1134.0;

// PWM lento
unsigned long windowSize = 8000; 
unsigned long windowStartTime;
unsigned long lastPidComputeTime = 0;
unsigned long pidSampleTime = 250; 

PID myPID(&Input, &Output, &Setpoint, Kp, Ki, Kd, DIRECT);

void setup() {
  Serial.begin(115200);
  delay(500);

  Setpoint = 50.0;   // temperatura alvo para o teste

  // Verifica termopar
  Input = thermocouple.readCelsius();
  while (isnan(Input)) {
    delay(2000);
    Input = thermocouple.readCelsius();
  }

  pinMode(RELAY_PIN, OUTPUT);
  digitalWrite(RELAY_PIN, LOW);

  myPID.SetOutputLimits(0, windowSize);
  myPID.SetSampleTime(pidSampleTime);
  myPID.SetMode(AUTOMATIC);

  windowStartTime = millis();
}

void loop() {
  unsigned long now = millis();

  // PID (a cada pidSampleTime = 250 ms)
  if (now - lastPidComputeTime >= pidSampleTime) {
    lastPidComputeTime = now;

    double tempC = thermocouple.readCelsius();

    if (!isnan(tempC))
      Input = tempC;
    else {
      // segurança: desliga SSR
      digitalWrite(RELAY_PIN, LOW);
    }

    myPID.Compute();
  }

  // IMPRESSÃO EM CSV PARA PuTTY (a cada 1 segundo)
  static unsigned long lastPrint = 0;
  if (now - lastPrint >= 1000) {    // <-- igual ao código 2
    lastPrint = now;

    // Formato: tempo(s),temperatura,setpoint
    Serial.print(now / 1000.0, 2);
    Serial.print(",");
    Serial.print(Input);
    Serial.print(",");
    Serial.println(Setpoint);
  }

  // PWM lento do SSR
  if (now - windowStartTime > windowSize)
    windowStartTime += windowSize;

  if ((now - windowStartTime) < Output)
    digitalWrite(RELAY_PIN, HIGH);
  else
    digitalWrite(RELAY_PIN, LOW);
}

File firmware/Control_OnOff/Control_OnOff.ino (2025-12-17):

#include <SPI.h>
#include <max6675.h>

const int thermoDO = 12;              
const int thermoCS = 10;              
const int thermoCLK = 13;             
const int SSR_PIN = 9;                
const unsigned long SAMPLE_MS = 1000; // agora imprime a cada 1s

double SETPOINT = 50.0;
double HYST = 0.5;

MAX6675 thermocouple(thermoCLK, thermoCS, thermoDO);

unsigned long lastSample = 0;
unsigned long elapsedSeconds = 0; // contador de tempo iniciado em 0
bool actuatorOn = false;

void setup() {
  Serial.begin(115200);
  pinMode(SSR_PIN, OUTPUT);
  digitalWrite(SSR_PIN, LOW);
  delay(500);

  thermocouple.readCelsius(); // descarta primeira leitura

  Serial.println("time_s,temperature_C,setpoint,actuator,event");
}

double readTempFiltered() {
  return thermocouple.readCelsius();
}

void setActuator(bool on) {
  actuatorOn = on;
  digitalWrite(SSR_PIN, on ? HIGH : LOW);
}

void loop() {
  unsigned long now = millis();
  if (now - lastSample >= SAMPLE_MS) {
    lastSample = now;

    elapsedSeconds++; // primeira impressão será 1s

    double T = readTempFiltered();

    // erro de leitura
    if (isnan(T)) {
      setActuator(false);
      Serial.print(elapsedSeconds);
      Serial.print(",nan,");
      Serial.print(SETPOINT);
      Serial.print(",0,ERROR_nan\n");
      return;
    }

    // controle ON/OFF com histerese
    if (!actuatorOn && T <= (SETPOINT - HYST)) {
      setActuator(true);
      Serial.print(elapsedSeconds);
      Serial.print(",");
      Serial.print(T, 3);
      Serial.print(",");
      Serial.print(SETPOINT);
      Serial.print(",");
      Serial.print(actuatorOn);
      Serial.println(",ON_from_below");
    }
    else if (actuatorOn && T >= (SETPOINT + HYST)) {
      setActuator(false);
      Serial.print(elapsedSeconds);
      Serial.print(",");
      Serial.print(T, 3);
      Serial.print(",");
      Serial.print(SETPOINT);
      Serial.print(",");
      Serial.print(actuatorOn);
      Serial.println(",OFF_from_above");
    }
    else {
      Serial.print(elapsedSeconds);
      Serial.print(",");
      Serial.print(T, 3);
      Serial.print(",");
      Serial.print(SETPOINT);
      Serial.print(",");
      Serial.print(actuatorOn);
      Serial.println(",");
    }
  }
}
